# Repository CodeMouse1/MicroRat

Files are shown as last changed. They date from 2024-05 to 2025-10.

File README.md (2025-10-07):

# MicroRat: Eine technische Dokumentation

<div align="center">
	

<div align="left">

Dieses Repository dokumentiert und bündelt das Projekt MicroRat – eine an der Micromouse orientierte Plattform für Studierenden der BHT.
Es stellt ein vollständiges Paket aus Hardware und Software-Komponenten bereit und soll als Grundlage für eigene Projekte, Experimente und Weiterentwicklungen dienen.
<div align="center">
	
<div align="left">
<br>
Wenn der Begriff einer Micromouse unbekannt ist findet man unter diesem Link ein Erläuterungsvideo:
[▶️](https://www.youtube.com/watch?v=ZMQbHMgK2rw)
<br>

## Technische Beschreibung
Micromouse ist ein internationaler Robotik-Wettbewerb, bei dem kleine, autonome Roboter ein Labyrinth selbstständig erkunden und den schnellsten Weg zum Ziel finden müssen.
Die Fahrzeuge agieren vollkommen ohne externe Hilfe und entscheiden selbstständig, wie sie Hindernisse und Wände erkennen.

_Die MicroRat soll als Einstieg in diese Thematik dienen._

**Hardware Umsetzung**

Das Aussehen einer Micromouse hängt stark vom jeweiligen Erbauer ab. Die MicroRat ist bewusst so gestaltet, dass sie grundlegende Funktionen mit einfacher Benutzbarkeit und Programmierbarkeit kombiniert.
Zur Umgebungserfassung kommen folgende Sensoren zum Einsatz:
###### Sensorik
- SHARP Infrarot-Sensoren, jeweils im 90°-Winkel senkrecht zu den Wänden montiert
- HC-SR04 Ultraschall-Sensor an der Vorderseite

###### Antrieb
- DC-Motoren mit Encodern für Antrieb und Drehzahlerfassung 

###### Stromversorgung
- 2s1p Li-Ion Akkupack für stabile Energieversorgung  

###### Steuerung & Schnittstellen

- XMC-1402 Mikrocontroller, programmierbar über Debug-Connector
- UART Schnittstelle zur Ausgabe der Sensordaten 

<div align="center">

<p float="center">
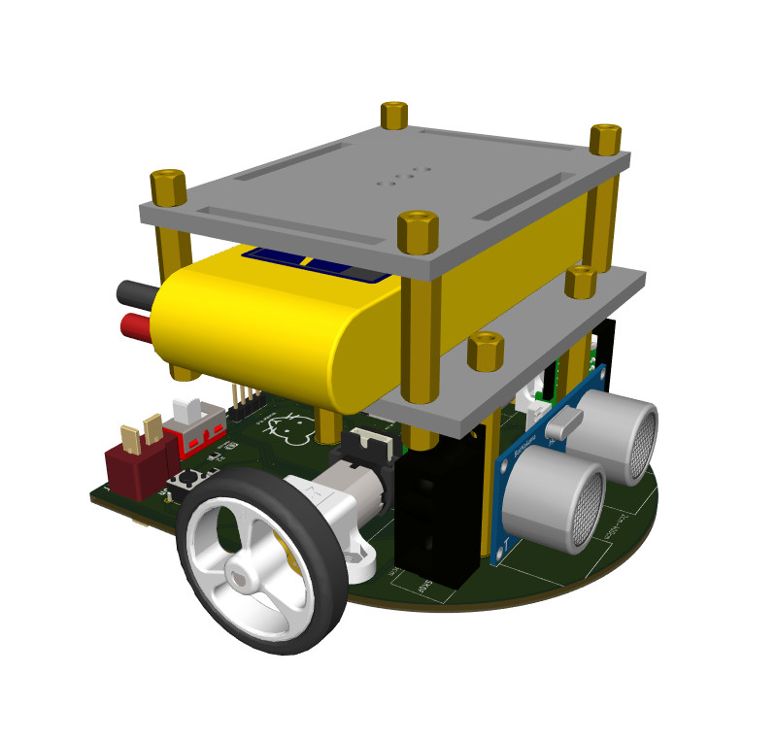
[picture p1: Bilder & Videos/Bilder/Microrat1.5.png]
  
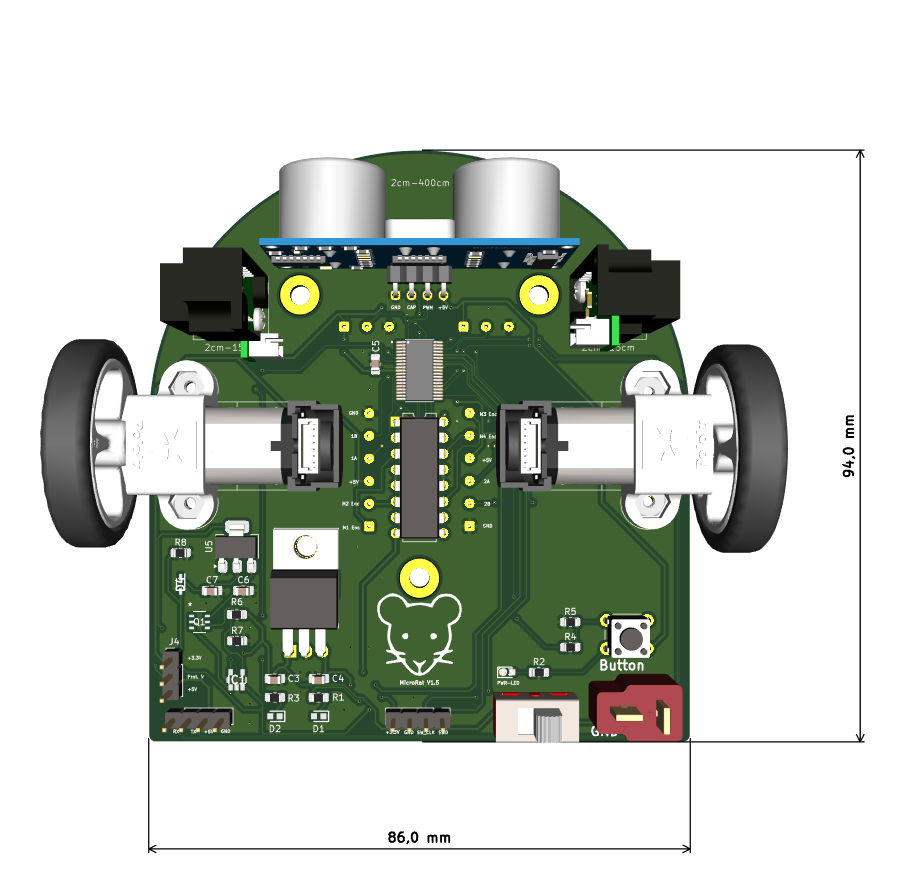
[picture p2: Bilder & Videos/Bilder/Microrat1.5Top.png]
   
</p>
Hier ein Link zu einer 3D Ansicht: [3D-Modell](https://a360.co/3VB2RBQ)
<div align="left">
<br>

**Software-Architektur**

Die MicroRat wird über den XMC-1402 Mikrocontroller gesteuert, der Sensoren ausliest, Motoren ansteuert und die Labyrinthnavigation übernimmt.

###### Entwicklungsumgebung
- **Sprache:** C
- **IDE:** DAVE™ 
- **Debugging:** Über den Debug-Connector des XMC4500

###### Hauptfunktionen
- **Sensordaten-Auswertung:** IR- und Ultraschallsensor erkennen Wände und Hindernisse
- **Motorsteuerung:** Drehzahlgeregelte Ansteuerung der DC-Motoren mittels PD-Regler
- **Labyrinth-Algorithmus:**
	- Wandfolger (links/rechts), kartografiert
	- Floodfill, Optimierung des schnellsten Weges zum Ziel
- **Kommunikation:** Sensordaten über UART für Debugging & Logging
<div align="center">

<p float="center">
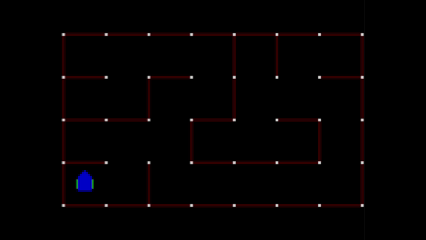
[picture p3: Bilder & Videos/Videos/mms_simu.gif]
  
</p>
<div align="left">

## Verwendung von KiCad 8.0
<div align="center">
	
<div align="left">
Für dieses Projekt haben wir KiCad 8.0 gewählt aus folgenden Gründen:
<br/><br/>

- **Fortschrittliche Funktionen:** Bietet erweiterte Tools für Schaltplanerstellung und Leiterplattendesign.
- **Open-Source-Software:** Kostenfrei und kontinuierlich verbessert durch eine große Community.
- **Plattformübergreifende Unterstützung:** Ermöglicht nahtlose Zusammenarbeit unabhängig vom Betriebssystem.

- **Kompatibilität und Exportmöglichkeiten:** Unterstützt viele Dateiformate und erleichtert die Integration mit anderen Tools.

Für eine grundlegende Einführung in KiCad bitte dieser Ratte folgen: [🐀](https://docs.kicad.org/)

## Anleitung

### Dave IDE 
<div align="center">
	
<div align="left">
<br>

DAVE IDE (Digital Application Virtual Engineering) ist eine benutzerfreundliche Entwicklungsumgebung für Mikrocontroller und eingebettete Systeme. Sie bietet Programmierung, Debugging und Analyse in einer Plattform.

###### Hauptfunktionen:

- **Projektverwaltung:** Projekte erstellen, importieren und konfigurieren.
- **Code-Editor:** Syntax-Highlighting, App-Help und Fehlererkennung.
- **Debugging:** Breakpoints setzen, Schritt-für-Schritt-Debugging, Variablen überwachen.

##### Erste Schritte mit DAVE IDE
- **Installation:**[⬇️](https://softwaretools.infineon.com/tools/com.ifx.tb.tool.daveide)
- **Projekt importieren:** Datei → Importieren → ZIP auswählen.

### Micromouse Simulator
<div align="center">
	
<div align="left">
<br>
Zum einfachen Testen und Erproben von Micromouse-Software ohne physische Hardware wird die Nutzung des MMS-Simulators empfohlen, mit dem Labyrinthe virtuell erstellt und Algorithmen sicher ausprobiert werden können: [Micromouse Simulator](https://github.com/mackorone/mms)

## Lizenzinformationen
Dieses Projekt ist Lizensiert unter der CC 4.0 Lizenz
https://creativecommons.org/licenses/by/4.0/

## Mitwirken
Wir freuen uns auf eure Erweiterungen! Wenn du an diesem Projekt mitarbeiten möchtest, folge bitte diesen Schritten:

1. **Fork dieses Repository**: Klicke oben rechts auf die Schaltfläche "Fork", um eine Kopie des Repositories in deinem GitLab-Konto zu erstellen.

2. **Clone das Forked Repository**: Klone dein geforktes Repository auf deinen lokalen Rechner.
    ```bash
    git clone https://github.com/dein-username/dein-repository.git
    ```

3. **Erstelle einen neuen Branch**: Erstelle einen neuen Branch für deine Arbeit.
    ```bash
    git checkout -b mein-neuer-branch
    ```

4. **Nimm deine Änderungen vor**: Führe die gewünschten Änderungen durch und committe sie.
    ```bash
    git add .
    git commit -m "Beschreibe deine Änderungen"
    ```

5. **Push deine Änderungen**: Push deine Änderungen zu deinem Fork.
    ```bash
    git push origin mein-neuer-branch
    ```

6. **Erstelle einen Pull Request**: Gehe zu deinem geforkten Repository auf GitLab und klicke auf die Schaltfläche "New Pull Request", um deine Änderungen zur Überprüfung einzureichen.

## Entwickler

Hardware & Software: Marcus Stake Alvarado

Ursprüngliches Hardware-Design: Nico Hinrichs

Ansprechprofessor: Prof. Dipl.-Ing. Koshan Mahdi

<div align="center">

**Viel Spaß mit der MicroRat**



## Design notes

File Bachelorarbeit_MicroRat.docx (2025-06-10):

Entwicklung und Implementierung eines effizienten Pfadfindungsalgorithmus für autonome Micromouse-Roboter in labyrinthartigen Umgebungen

Zwölfwöchige Abschlussarbeit im Rahmen der Prüfung

im Bachelorstudiengang Elektromobilität

an der Berliner Hochschule für Technik

vorgelegt am: 30.06.2025

von: Marcus Stake Alvarado

Matrikelnummer: 929605

1. Betreuer: Prof. Dipl.-Ing. Koshan Mahdi
2. Betreuer: Prof. Dr. Sven Graupner.

Berliner Hochschule für Technik

Vorwort

Diese Bachelorarbeit wäre ohne die Unterstützung von Prof. Dipl.-Ing. Koshan Mahdi und Prof. Dr. Sven Graupner nicht möglich gewesen. Mein besonderer Dank gilt ihnen für ihre fachliche Unterstützung, ihre wertvollen Anregungen sowie die vertrauensvolle Begleitung während der gesamten Bearbeitungszeit. Ein weiterer Dank richtet sich an Frank Stenzel, der mich insbesondere beim Aufbau meines Projektes tatkräftig unterstützt hat.

Diese Arbeit verwendet das generische Maskulinum, um die Lesbarkeit zu erhalten. Es sind dabei ausdrücklich alle Geschlechteridentitäten mitgemeint.

# Akronyme

C | Programmiersprache C
DAVE IDE | Development and Application Virtual Environment Integrated Development Environment
IR | Infrarot – ein Sensor, der zur Erkennung von Wänden und Hindernissen in der Nähe verwendet wird
Micromouse | Ein autonomer Roboter, der Labyrinthe selbstständig navigiert und deren Lösung findet
MicroRat | Bezeichnet das Projekt, das auf der Micromouse-Hardware basiert und speziell für den Einstieg in Embedded Systems und autonome Systeme konzipiert wurde.
PWM | Pulse Width Modulation - Ein Verfahren zur Erzeugung analog wirkender Spannungswerte durch digitale Signale, das unter anderem zur Geschwindigkeitsregelung von Motoren eingesetzt wird.
SLAM | Simultaneous Localization and Mapping (Simultane Lokalisierung und Kartierung)
UART | Universal Asynchronous Receiver-Transmitter – eine serielle Schnittstelle zur Kommunikation zwischen der MicroRat und externen Geräten
UML | Unified Modeling Language
US | Ultraschall – ein Sensor, der zur Messung von Abständen zu Hindernissen verwendet wird, insbesondere für die Frontnavigation der MicroRat.

# Glossar

Autonome Systeme | Systeme, die ohne menschliche Eingriffe Entscheidungen treffen und Aufgaben ausführen können
Eingebettete Systeme | Spezialisierte Computer, die in Geräten eingebaut sind, um bestimmte Funktionen auszuführen
Sensorik | Technik und Geräte, die physikalische Größen wie Temperatur, Abstand oder Bewegung messen
Aktuatorik | Technik und Geräte, die auf Basis von Sensorinformationen eine physikalische Bewegung oder Änderung hervorrufen
Mikrocontroller | Ein kleiner Computer auf einem einzigen Chip, der in eingebetteten Systemen verwendet wird
Timer/Interrupts | Mechanismen in Mikrocontrollern, die bestimmte Aktionen basierend auf Zeit oder Ereignissen auslösen
Wandverfolgung | Eine Navigationsstrategie für Roboter, bei der der Roboter kontinuierlich eine Wand entlang fährt, um sich zu orientieren
Maze-Solver | Ein Algorithmus oder eine Methode, die dazu verwendet wird, ein Labyrinth zu lösen
Git-Repository | Ein Speicherort für den Quellcode, der Versionierung und Zusammenarbeit ermöglicht.
Modularität | Der Aufbau eines Systems, bei dem einzelne Komponenten unabhängig voneinander entwickelt und ersetzt werden können.

# 1 Einleitung

Die autonome Navigation von Fahrzeugen und Robotern ist ein zentraler Pfeiler der modernen Elektromobilität. Eine der größten Herausforderungen in diesem Feld ist die Fähigkeit, sich in komplexen und unbekannten Umgebungen selbstständig zu orientieren [1]. Micromouse-Wettbewerbe, in deren Rahmen kleine Roboter labyrinthartige Strukturen durchqueren, stellen eine hervorragende und praxisnahe Plattform zur Erforschung grundlegender Prinzipien der autonomen Pfadfindung in einem kontrollierten Rahmen dar [2]. Die in diesem Kontext entwickelten effizienten Pfadfindungsalgorithmen sind nicht nur für diese spezifischen Roboter von Relevanz, sondern liefern auch wertvolle Erkenntnisse für die intelligente Steuerung und Routenoptimierung in größeren Systemen des autonomen Fahrens [3].

Der Fokus dieser Bachelorarbeit liegt auf der MicroRat-Plattform, einer im Rahmen einer studentischen Initiative an der Berliner Hochschule für Technik entwickelten Hardware-Komponente. Die Arbeit konzentriert sich explizit auf die Softwareentwicklung zur Pfadfindung, um die MicroRat zu einem voll funktionsfähigen Navigationssystem zu machen. Hierfür wurde zudem ein eigenes Labyrinth entworfen und gebaut, um eine maßgeschneiderte und reproduzierbare Testumgebung zu schaffen.

Die effiziente Pfadfindung in komplexen Labyrinthen stellt autonome Roboter vor signifikante Herausforderungen. Obwohl einfache Strategien wie der Wall Follower in grundlegenden Umgebungen effektiv sein können, stoßen sie bei zunehmender Komplexität oft an ihre Grenzen hinsichtlich der Lösungsgeschwindigkeit und Effizienz [4]. Dies ist insbesondere vor dem Hintergrund der limitierten Rechenressourcen und Sensorkapazitäten kleiner autonomer Plattformen wie der MicroRat zu berücksichtigen [5].

Ziel dieser Bachelorarbeit ist daher die Entwicklung und Implementierung von Wall Follower Algorithmen für die MicroRat-Plattform, gefolgt von einer Pfadoptimierung mittels des Flood Fill Algorithmus nach der Erkundung des Labyrinths. Ein zentraler Aspekt dieser Arbeit ist die Konzeption einer klaren und nachvollziehbaren Softwarearchitektur. Diese soll nicht nur die optimale Anpassung der Algorithmen an die bestehende Hardware und die reibungslose Integration mit den vorhandenen Sensoren und der Steuerungseinheit sicherstellen, sondern auch als verständliche Grundlage für zukünftige studentische Projekte an der MicroRat-Plattform dienen.

## 1.1 Motivation

Die Motivation für diese Bachelorarbeit basiert auf dem besonderen Reiz von Micromouse-Robotern, die verschiedene Kernbereiche wie Elektrotechnik, Informatik und Robotik auf einzigartige Weise vereinen. Die Interdisziplinarität des Themas bietet eine ideale Grundlage für eine Vertiefung im Rahmen des Studiengangs Elektromobilität.

Ein wesentliches Ziel bestand zudem darin, einen praktischen Beitrag zur MicroRat-Plattform zu leisten. Die Konzeption einer robusten und nachvollziehbaren Gesamtbasis (Hard- und Software) zielt darauf ab, zukünftigen Studierenden den Einstieg in die autonome Robotik zu erleichtern. Die geschaffene Plattform dient als Fundament, um typische Sensoren, Komponenten und Navigationsalgorithmen zu erlernen und weitere Entwicklungen auf der MicroRat zu ermöglichen.

## 1.2 Problemstellung

Die effiziente Navigation autonomer Roboter in komplexen Labyrinthen ist mit spezifischen Herausforderungen verbunden. Bei der Erkundung unbekannter Umgebungen können grundlegende Strategien wie der Wall Follower eine erste Orientierung bieten, jedoch sind sie allein hinsichtlich der Lösungsgeschwindigkeit und Effizienz bei steigender Komplexität oft unzureichend. Diese Limitierungen werden zusätzlich durch die begrenzten Rechenressourcen und Sensorkapazitäten kleiner autonomer Plattformen, wie der in dieser Arbeit genutzten MicroRat, verstärkt. Es bedarf somit einer Kombination aus geeigneten Erkundungs- und Optimierungsalgorithmen, die diesen Restriktionen gerecht werden und eine effiziente Pfadfindung ermöglichen.

Des Weiteren existierte bisher keine zentrale und umfassende studentische Plattform (bestehend aus Hard- und Software), die speziell darauf ausgelegt ist, Studierenden den Einstieg in die Entwicklung und Erprobung autonomer Navigation zu erleichtern. Dies erschwert es, die notwendigen praktischen Erfahrungen im Zusammenspiel von Sensorik, Bewegungsteuerung und komplexen Navigationsalgorithmen zu sammeln und eigenständig weiterzuentwickeln. Eine schnelle und zuverlässige Pfadfindung in anspruchsvollen Umgebungen erfordert daher nicht nur die Implementierung leistungsfähiger Algorithmen, sondern auch die Bereitstellung einer zugänglichen und nachvollziehbaren Gesamtplattform, die als Basis für zukünftige Projekte und Lehrzwecke dienen kann.

## 1.3 Zielsetzung

Das übergeordnete Ziel dieser Bachelorarbeit ist die Entwicklung und Implementierung einer effizienten und nachvollziehbaren Navigationslösung für die MicroRat-Plattform, die sowohl technische Herausforderungen meistert als auch als didaktische Grundlage dient. Um dieses Hauptziel zu erreichen, werden folgende spezifische Ziele verfolgt:

- Entwicklung und Implementierung von Wall Follower Algorithmen für die MicroRat-Plattform zur initialen Labyrinth Exploration.
- Pfadoptimierung der erkundeten Labyrinthe mittels des Flood Fill Algorithmus, um die Effizienz der Navigation zu maximieren.
- Konzeption und Umsetzung einer klaren und modularen Softwarearchitektur, die eine optimale Anpassung der Algorithmen an die bestehende MicroRat-Hardware ermöglicht und die reibungslose Integration aller Sensoren und der Steuerungseinheit sicherstellt.
- Entwurf und Bau eines maßgeschneiderten Labyrinths als dedizierte Testumgebung für die Validierung der entwickelten Navigationsalgorithmen.
- Bereitstellung einer vollständigen und dokumentierten Gesamtplattform (Hard- und Software), die zukünftigen Einstieg in die Entwicklung und Erprobung autonomer Micromouse-Roboter ermöglicht und als fundierte Basis für weiterführende Projekte und Lehre an der Berliner Hochschule für Technik dienen kann.

## 1.4 Vorgehensweise

Die vorliegende Arbeit wird in mehrere Kapitel unterteilt:

Kapitel 1: Einleitung
Dieses Kapitel führt in die Problemstellung, die Zielsetzung und die Motivation der Arbeit ein. Es erläutert den Kontext und die Relevanz des Projekts sowie die Vorgehensweise vor.

Kapitel 2: Grundlagen
In diesem Kapitel werden die theoretischen Grundlagen und relevanten Konzepte erläutert, die für das Verständnis der Arbeit erforderlich sind.

Kapitel 3: Anforderungsanalyse
In diesem Kapitel wird die Zielgruppe des Projekts analysiert, für die die Software entwickelt wurde. Auf Grundlage dieser Zielgruppenanalyse werden die spezifischen Anforderungen an die zu entwickelnde Software abgeleitet und formuliert.

Kapitel 4: Entwurf
In diesem Kapitel wird der Entwurf des Pfadfindungsalgorithmus für den autonomen Micromouse-Roboter, die Softwarearchitektur sowie die Struktur der labyrinthartigen Umgebung beschrieben.

Kapitel 5: Implementierung
In diesem Kapitel wird die Implementierung der entwickelten Software detailliert beschrieben. Es wird auf die Struktur des Projekts eingegangen, die wesentlichen Schritte der Code-Entwicklung erläutert.

Kapitel 6: Validierung und Evaluation
In diesem Kapitel wird die Umsetzung der im Kapitel 3 festgelegten Anforderungen überprüft. Die tatsächliche Realisierung wird mit den definierten Anforderungen abgeglichen und hinsichtlich ihrer Funktionsfähigkeit sowie Effektivität evaluiert.

Kapitel 7: Fazit und Ausblick
In diesem Kapitel werden die Ergebnisse der Arbeit zusammengefasst und die Zielerreichung reflektiert. Zudem werden mögliche Perspektiven für zukünftige Entwicklungen und Optimierungen des entwickelten Systems aufgezeigt.

# 2 Grundlagen

## 2.1 Micromouse-Plattform

Ein Micromouse ist ein autonomer, selbstständiger Roboter, der entwickelt wird, um das Zentrum eines Labyrinths in der kürzest möglichen Zeit zu erreichen. Der Roboter besteht typischerweise aus drei Hauptsystemen: dem Antriebssystem, einem Array von Sensoren und dem Steuerungssystem. Diese Systeme arbeiten zusammen, um dem Roboter zu ermöglichen, das Labyrinth zu erkunden, Wände zu erkennen und die optimale Route zu finden. Die grundlegenden Komponenten umfassen Motoren für den Antrieb, Steuermechanismen für das Drehen und Lenken, Sensoren zur Erkennung von Labyrinthwänden sowie eine Steuerlogik, die die Bewegungen überwacht und die Navigation im Labyrinth ermöglicht. Darüber hinaus ist der Micromouse mit Batterien ausgestattet, die die notwendige Energie für seine Operationen liefern. Es vereint interdisziplinäre ingenieurwissenschaftliche Aspekte, darunter Elektronik, Mechanik, Steuerungstechnik und Programmierung. Die Entwürfe der erfolgreichsten Micromouse-Roboter erfordern eine präzise Abstimmung der Komponenten, um das Gewicht, die Geschwindigkeit und die Energieeffizienz zu optimieren. Besonders hervorzuheben ist die Bedeutung von Entscheidungsfindungsalgorithmen, die es dem Roboter ermöglichen, in unbekannten Umgebungen autonom zu navigieren. Für Anfänger im Bereich Micromouse wird häufig mit einfachen Logiken begonnen, wie etwa der Wandfolgetechnik, die später durch anspruchsvollere Algorithmen wie Pfadfindungsstrategien ersetzt wird [1].

### 2.1.1 Geschichte der Micromouse-Wettbewerbe

Die Micromouse-Wettbewerbe wurden erstmals 1979 von der IEE Spectrum Magazine ins Leben gerufen, nachdem 1972 die Idee eines mechanischen Rennmaus-Wettbewerbs entstand. Der erste Wettbewerb fand 1979 in New York statt, bei dem 6.000 Einsendungen verzeichnet wurden, aber nur 15 Mäuse tatsächlich teilnahmen. Die Wettbewerbe begannen auf 8x8-Labyrinthen, wobei die schnellsten Mäuse Zeiten von etwa 30 Sekunden erreichten [2]. Der Sieger war 'Moonlight Flash', eine einfache Wandfolgemaschine. In den folgenden Jahren wurden die Wettbewerbsregeln zunehmend anspruchsvoller, was dazu führte, dass die Entwickler intelligentere Mäuse bauten, die in der Lage waren, das Labyrinth eigenständig zu lösen [1].

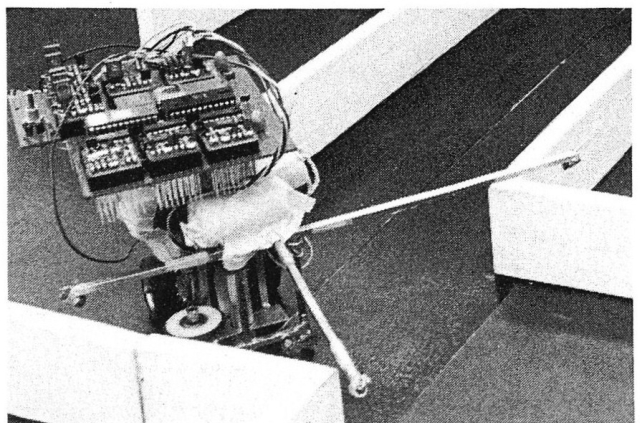
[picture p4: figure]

Abbildung 1: „Moonlight Flash“ – Micromouse, 1979

Die erste europäische Micromouse-Veranstaltung fand 1980 in London statt, und 1985 wurde der erste Welt-Micromouse-Wettbewerb in Japan ausgetragen. Ab den 1990er Jahren begannen Micromouse-Clubs an Schulen zu entstehen, und 1991 wurden die Wettbewerbsregeln geändert, um nicht nur die Geschwindigkeit, sondern auch die Zuverlässigkeit der Mäuse zu betonen [1]. Heute, mehr als vier Jahrzehnten später, haben sich die Wettkämpfe weltweit verbreitet und sind besonders in Japan, Taiwan, Indonesien, Großbritannien und den USA populär. Die Labyrinthe bestehen inzwischen aus 16x16 Zellen, und die besten Mäuse erreichen Rennzeiten von weniger als 7 Sekunden bei Strecken von über 70 Zellen. Diese Rekordzeiten entsprechen einer Geschwindigkeit von 2 bis 4 Metern pro Sekunde. Die Wettbewerbe haben sich so weit entwickelt, dass führende Micromouse-Designer das ganze Jahr über an Verbesserungen im Bereich der Hundertstelsekunden arbeiten [2].

Im Jahr 2009 entschieden die Veranstalter in Japan, eine neue Herausforderung zu schaffen: Die Half-Size Micromouse. Die Regeln und das Ziel bleiben nahezu gleich, aber die Baugröße wurde auf die Hälfte reduziert. Diese kleinere Variante stellt die Designer vor neue Herausforderungen, insbesondere im Hinblick auf die Miniaturisierung der Komponenten. Dank der Entwicklungen in der Smartphone- und Drohnentechnologie ist es mittlerweile möglich, bemerkenswert kompakte und komplexe Roboter zu bauen [2].

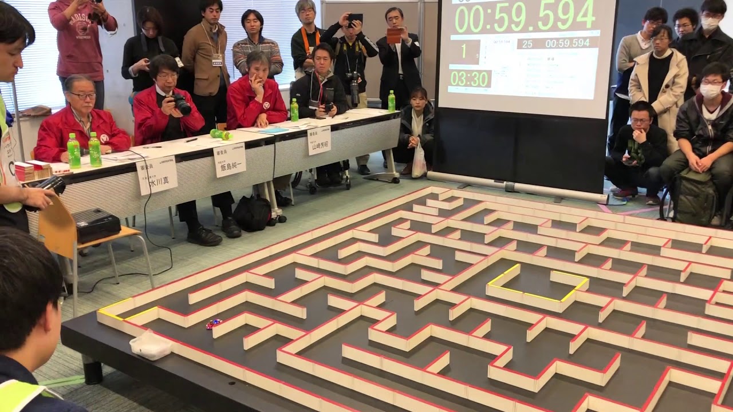
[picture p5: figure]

Abbildung 2: „赤い彗星 (Red Comet)“ – 1. Platz, All Japan Classic Micromouse Contest 2017, von Utsunomiya-san

## 2.2 Aufbau der MicroRat Plattform

Die Hardware eines Micromouse besteht im Wesentlichen aus fünf Hauptkomponenten: Sensoren, Leiterplatte, Energieversorgung, Mikrokontroller und Antriebssystem (siehe Abb. 3). Diese Systeme arbeiten eng zusammen, um eine effiziente und präzise Funktionalität zu gewährleisten [1].

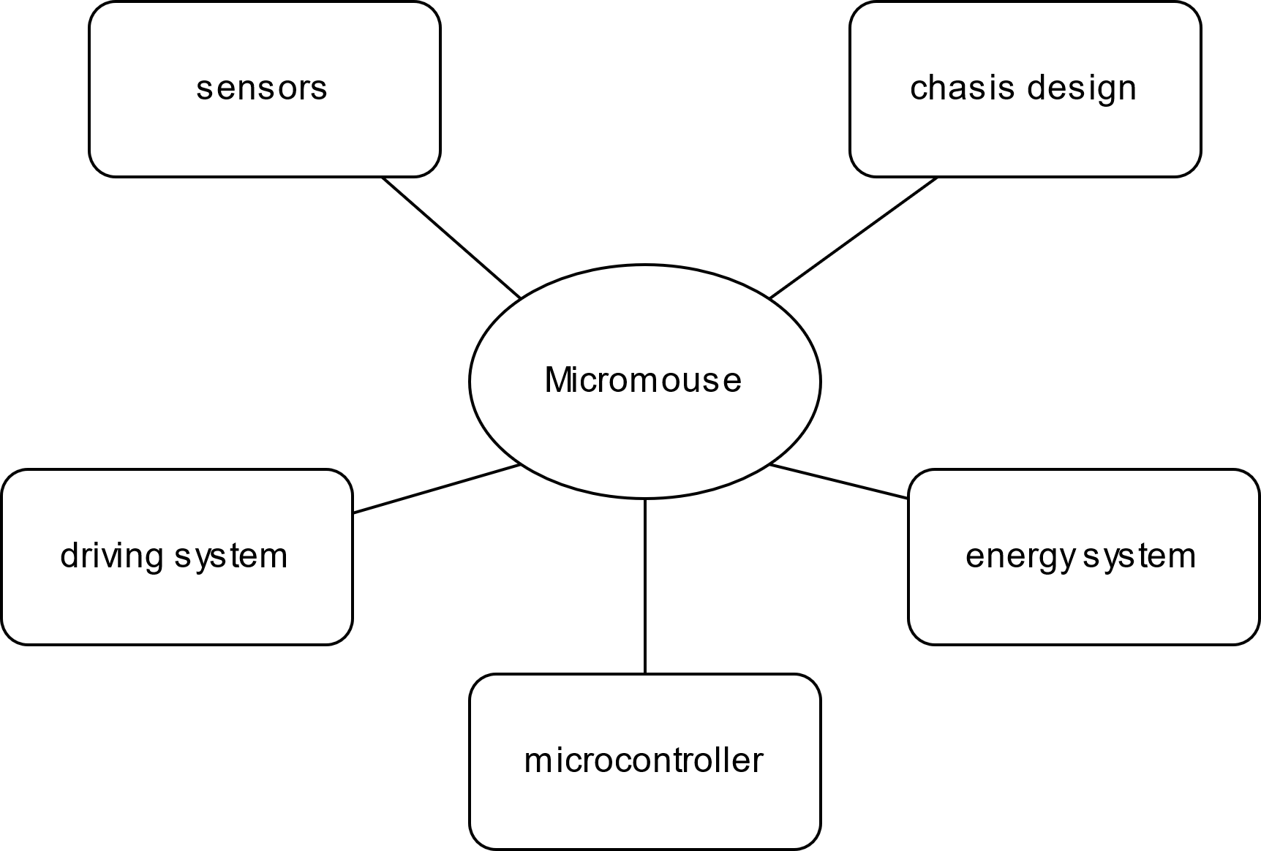
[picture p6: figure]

Abbildung 3: Blockdiagramm einer Micromouse Allgemein

Die MicroRat-Plattform, die bereits im 6. Semester im Rahmen der Steuergeräteentwicklung konzipiert und entwickelt wurde, basiert auf diesen grundlegenden Prinzipien. In den folgenden Abschnitten wird auf die einzelnen Komponenten der MicroRat näher eingegangen, um die Funktionalität und Integration der Hardware zu verdeutlichen.

### 2.2.1 Sensorik

Die Sensoren eines autonomen mobilen Roboters sind entscheidend für die Wahrnehmung und Interaktion mit seiner Umgebung. In einer Micromouse, wie auch in anderen autonomen Systemen, ermöglichen Sensoren das Erfassen von Umgebungsdaten, die für die Navigation und Entscheidungsfindung unerlässlich sind. Ohne diese Wahrnehmungsfähigkeit wären die erfassten Daten lediglich bedeutungslose Zahlen, die keinen Einfluss auf das Verhalten des Roboters hätten [3]. Ähnlich wie in biologischen Systemen, in denen visuelle Wahrnehmung eine wichtige Quelle der Navigation und Planung darstellt [3], nutzt die MicroRat Sensoren zur Umgebungserfassung.

Die Sicht der MicroRat wird durch eine Kombination aus Licht- und Schallsensoren simuliert, die es dem Roboter ermöglichen, auf Objekte und Veränderungen in seiner Nähe zu reagieren. Besonders in der Navigations- und Hindernisvermeidungsphase spielen Infrarot- und Ultraschallsensoren eine entscheidende Rolle, da sie dem Roboter helfen, Entfernungen präzise zu messen und Hindernisse zuverlässig zu detektieren [4]. Im Folgenden werden wir uns näher mit den Funktionen und Vorteilen von Infrarot- und Ultraschallsensoren in autonomen Systemen wie der MicroRat befassen.

Infrarot Sensoren (IR)

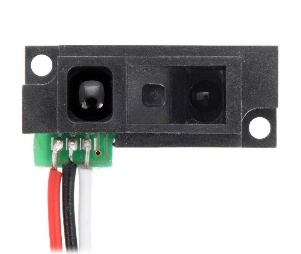
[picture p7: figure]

Abbildung 4: Infrarotsensor GP2Y0A51SK0F

Infrarotsensoren werden häufig in der Robotik eingesetzt, um Entfernungen zu messen, und sind besonders nützlich bei der Hindernisvermeidung. Im Vergleich zu Ultraschallsensoren sind sie kostengünstiger und reagieren schneller. Allerdings weisen IR-Sensoren nichtlineare Charakteristiken auf und ihre Leistung hängt von den Reflexionseigenschaften der Oberflächen ab. Das bedeutet, dass die Beschaffenheit der Oberfläche, die das Infrarotlicht reflektiert oder absorbiert, bekannt sein muss, um die Sensormessungen korrekt zu interpretieren [5]. Die Funktionsweise eines IR-Sensors basiert auf zwei Hauptkomponenten: einem Infrarot-LED-Emitter und einem Infrarot-Fotodetektor. Der Emitter sendet Infrarotlicht aus, das von Objekten in der Umgebung reflektiert wird. Das reflektierte Licht trifft auf einen Positionsdetektor (PSD). Je nach Entfernung des Objekts verändert sich der Einfallswinkel des reflektierten Lichts, wodurch sich die Auftreffposition auf dem Detektor verschiebt. Der Sensor ermittelt aus dieser Position die Entfernung zum Objekt mittels Triangulation [6]. Ein spezifischer Sensor, der in der MicroRat verwendet wird, ist der Sharp GP2Y0A51SK0F. Dieser Sensor verwendet die zuvor beschriebene Triangulationsmethode, bei der der Abstand durch das reflektierte Infrarotlicht bestimmt wird. Der Sensor führt die Entfernungsmessung intern durch. Eine direkte Berechnungsformel existiert nicht; stattdessen korreliert die analoge Ausgangsspannung mit der Entfernung entsprechend einer herstellerspezifischen Kennlinie [6].

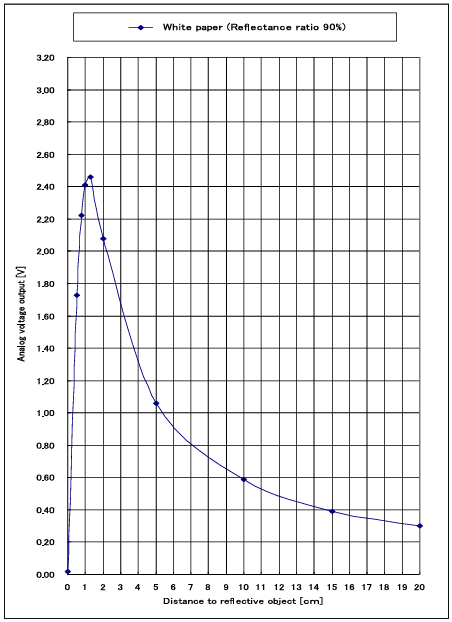
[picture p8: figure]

Abbildung 5: Spannung in Relation zur Distanz des Sharp GP2Y0A51SK0F Infrarotsensors

Der GP2Y0A51SK0F bietet eine Reichweite von 2 cm bis 15 cm und liefert eine hohe Auflösung bei kurzen Distanzen. Das Ausgangssignal des Sensors ist eine analoge Spannung, die direkt mit der Entfernung korreliert [6]. Diese Spannung wird von einem Analog-Digital-Wandler (ADC) in der MicroRat aufgenommen, der das analoge Signal in digitale Werte umwandelt. Diese digitalen Werte können dann vom Mikrocontroller der MicroRat-Plattform weiterverarbeitet werden. In der MicroRat-Plattform sind zwei dieser IR-Sensoren in einem 45°-Winkel an der Vorderseite montiert. Diese Position ermöglicht es, die Wände des Labyrinths zu erfassen und Hindernisse effektiv zu erkennen, was eine präzise Navigation innerhalb der engen Gänge ermöglicht.

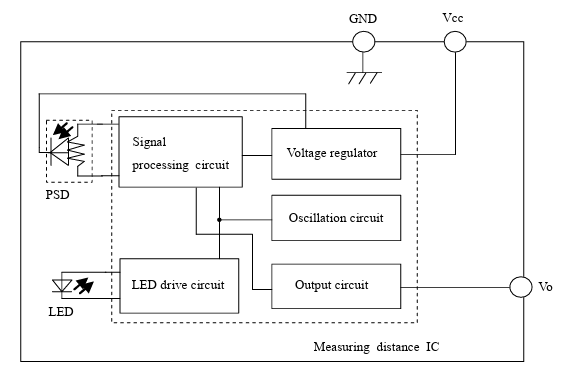
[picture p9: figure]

Abbildung 6: Schaltplan GP2Y0A51SK0F

Ultraschallsensor

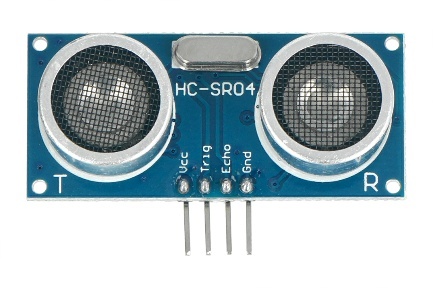
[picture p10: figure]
Ultraschall-Abstandssensor HC-SR04 2-400 cm - SparkFun SEN-15569

Abbildung 7: Ultraschallsensor HC-SR04

Ultraschallsensoren sind in der Robotik weit verbreitet und werden häufig für kontaktlose, mittlere Entfernungsabstände verwendet. Diese Sensoren kommen insbesondere in Navigationssystemen für mobile Roboter und Fahrzeuge zum Einsatz. Ultraschallsensoren nutzen die Time of Flight (TOF) Methode zur Entfernungsmessung, bei der die Zeit gemessen wird, die ein Ultraschallimpuls benötigt, um von einem Sender zu einem Objekt und zurück zum Empfänger zu reisen. Diese Methode ermöglicht eine präzise Entfernungsmessung und ist besonders geeignet für die Hinderniserkennung und -vermeidung [4]. Ein Ultraschallsensor funktioniert, indem er eine Schallwelle mit einer bestimmten Frequenz aussendet. Der Sensor hört dann nach dieser speziellen Schallwelle, die von einem Objekt zurückprallt. Die Zeit, die zwischen dem Senden der Schallwelle und dem Zurückkehren der Schallwelle vergeht, wird dabei erfasst (siehe Abbildung 1) [4].

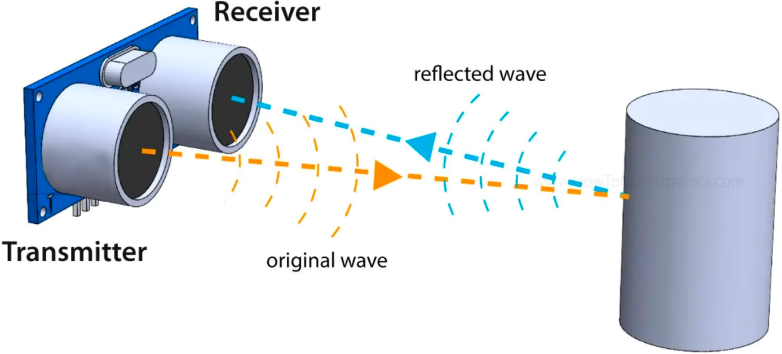
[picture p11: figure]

Abbildung 8: Funktionsweise HC-SR04

Mit dieser Zeitmessung lässt sich die zurückgelegte Strecke berechnen, indem die Geschwindigkeit der Schallwelle (v) mit der gemessenen Zeit (t) multipliziert wird, wie in Gleichung 2.2.1 gezeigt:

d=v*t

Dabei steht d für die zurückgelegte Entfernung, v für die Geschwindigkeit der Schallwelle und t für die benötigte Zeit. Der HCSR04 Ultraschallsensor kann durch Setzen des TRIG-Pins auf HIGH ausgelöst werden, um einen Ultraschallimpuls zu senden. Nachdem der Impuls gesendet wurde, wird der ECHO-Pin automatisch auf HIGH gesetzt. Dieser Pin bleibt so lange auf HIGH, bis der Schallimpuls wieder vom Objekt reflektiert und zum Sensor zurückkehrt. Die Distanz zum Objekt kann berechnet werden, indem man die Zeit misst, in der der ECHO-Pin auf HIGH bleibt. Diese Zeit entspricht der Dauer, die der Schallimpuls für seine Hin- und Rückreise benötigt. Mithilfe dieser Zeit und der Geschwindigkeit des Schalls lässt sich die zurückgelegte Entfernung berechnen [4].

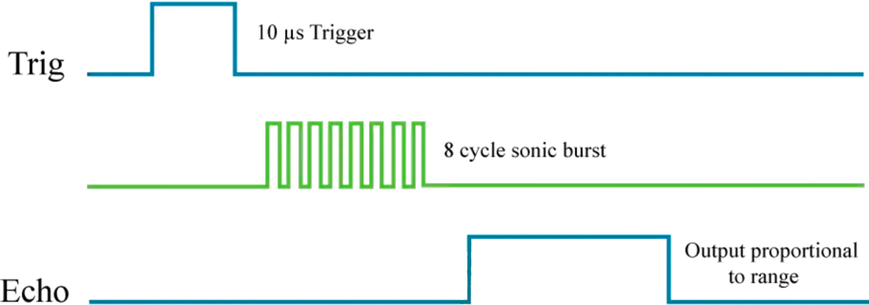
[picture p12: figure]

Abbildung 9: Timing Diagramm HC-SR04

Da die Zeitmessungseinheit des Sensors in Mikrosekunden erfolgt, ist es notwendig, die Schallgeschwindigkeit zu berücksichtigen, die unter Standardbedingungen (bei 20°C und 1013 hPa) etwa 343 Meter pro Sekunde beträgt [3]. Zur praktischen Umrechnung dieser Geschwindigkeit in geeignete Maßeinheiten für die Distanzmessung wird die Schallgeschwindigkeit in Mikrosekunden pro Zentimeter umgerechnet.

Schallgeschwindigkeit=343m/s*(100cm/m*10^6 μs)/s=170.15μs/c

d=(t*170.15μs/cm)/2

Diese Umrechnungen ermöglichen eine präzise Bestimmung der Entfernung in Zentimetern basierend auf der gemessenen Zeit und der bekannten Schallgeschwindigkeit [4]. In der MicroRat-Plattform ist ein HC-SR04 Ultraschallsensor an der Vorderseite montiert, um Hindernisse zu erkennen und eine präzise Navigation zu ermöglichen.

Encoder und Positionsbestimmung

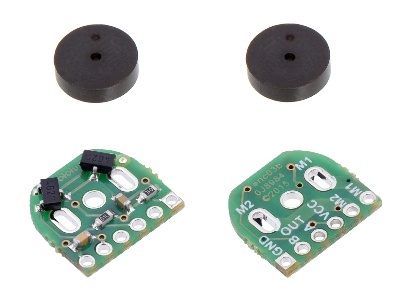
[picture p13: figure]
Pololu - Magnetic Encoder Pair Kit for Micro Metal Gearmotors, 12 CPR, 2.7-18V

Abbildung 10: Encoder Paar in MicroRat

Odometrie bezeichnet die Positions- und Orientierungsbestimmung eines Roboters anhand von Antriebsdaten. Dabei werden Radabstand, Radumfänge und die Motorumdrehungen ausgewertet, um zurückgelegte Strecken und Drehungen zu berechnen [4]. Zur Erfassung der Drehbewegungen werden sogenannte Shaft-Encoder verwendet. Ein Shaft-Encoder ist ein Sensor, der mechanisch mit einer rotierenden Welle (Shaft) verbunden wird und elektrische Signale an ein Logiksystem sendet [7].

Im Rahmen dieser Arbeit wird der Encoder-Typ, der in der MicroRat-Plattform verwendet wird, detailliert betrachtet. Andere Encoder-Typen, die nicht in dieser Plattform zum Einsatz kommen, werden nicht weiter behandelt, da sie für die spezifische Analyse der Odometrie und Navigation des Roboters nicht relevant sind. Bei dem in der MicroRat-Plattform verwendeten Encoder handelt es sich um einen magnetischen inkrementellen Quadratur-Encoder. Im Folgenden wird die Funktionsweise dieses Encoders erläutert.

Magnetische Encoder

Magnetische Encoder nutzen magnetische Felder, die von einem Sensor erfasst werden. Eine magnetische Scheibe oder ein Magnetband dreht sich mit der Welle, und der Sensor registriert die Veränderungen im Magnetfeld, die durch die Bewegung des Lesekopfs entstehen. Diese Änderungen im Magnetfeld werden vom Sensor detektiert und in ein elektrisches Signal umgewandelt [6].

Inkremental und Quadratur Encoder

Ein Inkremental-Encoder ist ein elektromechanisches Bauteil, das lineare oder rotatorische Bewegungen erfasst und zwei Ausgangssignale (A und B) generiert, die bei Bewegung Impulse erzeugen. Anhand der beiden um 90° phasenverschobenen Signale können sowohl Bewegungsänderungen als auch die Bewegungsrichtung bestimmt werden. Im Gegensatz zu einem Absolut-Encoder liefert ein Inkremental-Encoder keine absolute Positionsinformation, sondern lediglich relative Positionsänderungen. Um daraus eine absolute Position zu bestimmen, müssen die ausgegebenen Impulse durch eine geeignete Auswerteelektronik kontinuierlich gezählt werden [7].

Ein Quadratur-Encoder ist eine spezielle Form des Inkremental-Encoders. Er besitzt zwei phasenverschobene Ausgangssignale (A und B), anhand derer nicht nur die Bewegungsänderung, sondern auch die Bewegungsrichtung zuverlässig ermittelt werden kann. Die Phasenlage der Signale ermöglicht es, Drehbewegungen präzise aufzulösen und Richtungswechsel sicher zu erkennen [6].

Funktionsweise des magnetischen inkrementalen Quadratur-Encoders

Der in der MicroRat-Plattform eingesetzte Encoder kombiniert die Prinzipien der magnetischen Erfassung mit der Inkremental- und Quadratur-Technologie. Eine auf der Motorwelle montierte magnetische Scheibe erzeugt ein rotierendes Magnetfeld [6]. Zwei gegenüberliegend angebrachte Hallsensoren erfassen die Veränderungen dieses Magnetfelds und generieren daraus zwei elektrische Signale (A und B), die um 90° phasenverschoben sind [6].

Durch die Auswertung der Signalflanken lässt sich nicht nur die Anzahl der Drehbewegungen (Impulse), sondern auch die Drehrichtung der Welle bestimmen. Die Encoder liefern Impulse, die in Kombination mit der Drehrichtung genutzt werden, um die Bewegungen des Roboters zu erfassen. Diese Informationen werden später zur Berechnung der zurückgelegten Strecke und der Orientierung verwendet.

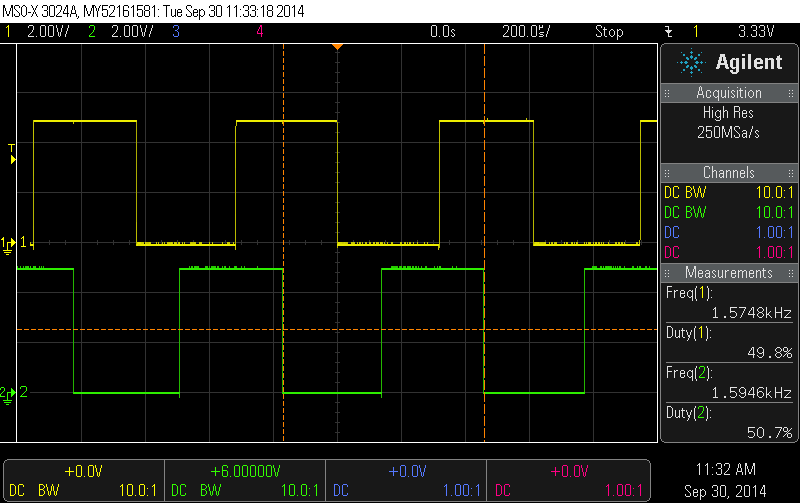
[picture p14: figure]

Abbildung 11: Ausgänge A und B des magnetischen Encoders bei 6V Motorspannung

### 2.2.2 Motorenansteuerung

Der Bewegungsmechanismus eines mobilen Roboters wird maßgeblich durch seinen Antriebsstrang bestimmt, der sich aus den Motoren und dem Motorcontroller zusammensetzt. Die Auswahl der Motoren für eine Micromouse ist von entscheidender Bedeutung, da sie zahlreiche Parameter beeinflusst und sowohl das Gewicht als auch die Leistungsfähigkeit der Micromouse wesentlich bestimmt [8]. Der am häufigsten verwendeter Aktuator in mobilen Robotern ist der Elektromotor, wobei in der Regel Gleichstrommotoren oder Schrittmotoren zum Einsatz kommen. Gleichstrommotoren gelten als besonders einfach zu steuern, da sie bereits durch das Anlegen von Gleichstrom betrieben werden können [8]. Da in der MicroRat-Plattform ein Gleichstrommotor verwendet wird, wird die grundlegende Funktionsweise im Folgenden näher erläutert.

Die grundlegenden Mechanismen der Bewegung sind bei verschiedenen Gleichstrommotoren ähnlicher Natur. Die von diesen Elektromotoren erzeugte Bewegung beruht auf wesentlichen physikalischen Prinzipien wie der Lorentzkraft und der elektromagnetischen Induktion [9]. Gleichstrommotoren mit Bürsten bestehen aus vier Hauptkomponenten: dem stationären Magneten (Stator), dem Rotor, dem Kommutator und den Bürsten. Der Rotor umfasst eine oder mehrere Drahtwicklungen, die um einen ferromagnetischen Kern, meist aus Eisen, gewickelt sind. Über die Bürsten wird elektrischer Strom in die Rotorwicklungen eingespeist. Das dabei entstehende Magnetfeld des Rotors interagiert mit dem Magnetfeld des Stators und erzeugt eine Kraft, die Lorentzkraft, welche den Rotor in Drehbewegung versetzt. Der Stator kann je nach Anforderung entweder aus Permanentmagneten oder Elektromagneten bestehen. Ohne eine gezielte Steuerung der Stromrichtung würde sich das Magnetfeld des Rotors beim Weiterdrehen umkehren, was lediglich zu einer Hin- und Herbewegung führen würde. Um eine kontinuierliche Rotation zu ermöglichen, wird ein Kommutator eingesetzt. Dieser elektrisch und mechanisch segmentierte, leitfähige Ring ist am Rotor angebracht und sorgt zusammen mit den Bürsten dafür, dass die Polarität der Rotorwicklungen periodisch umgekehrt wird. Auf diese Weise wird eine gleichmäßige, kontinuierliche Drehbewegung erreicht [9].

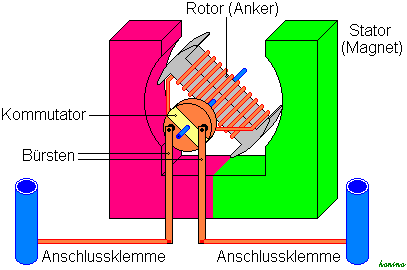
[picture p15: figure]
gleichstrommotor [elweb]

Abbildung 12: PLATZHALTER

Für die MicroRat-Plattform ist es entscheidend, dass der Motor sowohl die Geschwindigkeit als auch die Drehrichtung präzise steuern kann. Die Geschwindigkeit des Motors wird in der Regel über Pulsweitenmodulation (PWM) geregelt. Diese Methode ist besonders effizient, da sie die durchschnittliche Spannung, die an den Motor angelegt wird, durch schnelles Ein- und Ausschalten des Stroms reguliert. Auf diese Weise kann die Drehzahl des Motors gesteuert werden, ohne dass Energie durch Widerstände oder andere Verluste dissipiert wird, wie es bei herkömmlichen Spannungsteilern der Fall wäre.

Um die Drehrichtung des Motors zu ändern, wird in der MicroRat-Plattform eine H-Brücke verwendet. Diese Schaltung besteht aus vier Transistoren, die es ermöglichen, den Stromfluss durch den Motor in beide Richtungen umzuleiten. Indem man die richtigen Transistoren an- und ausschaltet, kann die MicroRat vorwärts oder rückwärts fahren.

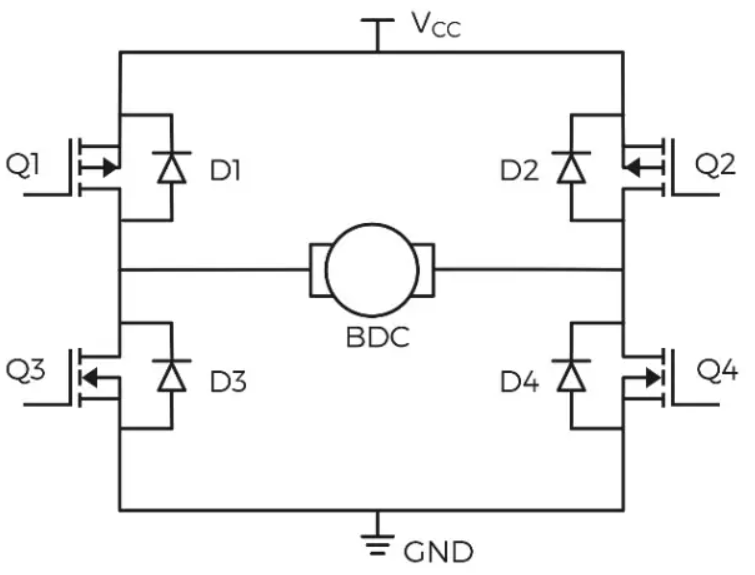
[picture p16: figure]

Abbildung 13: etst

### 2.2.2 Mikrocontroller und DAVE IDE

Das zentrale Steuerelement der MicroRat-Plattform bildet der Mikrocontroller XMC1402-T038X0128 AA von Infineon. Dieser Mikrocontroller basiert auf einem 32-Bit ARM® Cortex®-M0-Prozessorkern und vereint Rechenleistung, Speicher und zahlreiche Peripherieeinheiten in einem kompakten Baustein. Er ist speziell für Embedded-Anwendungen im Bereich Motorsteuerung, Sensoranbindung und allgemeiner Steuerungsaufgaben konzipiert und eignet sich daher ideal für den Einsatz in einer autonomen MikroRat. [Quelle]. Der Mikrocontroller übernimmt im Gesamtsystem zentrale Aufgaben wie die Verarbeitung der Sensordaten, die Ansteuerung der Motoren sowie die Ausführung von Steuer- und Regelalgorithmen. Durch die Vielzahl integrierter Peripherieeinheiten kann die Kommunikation mit der Sensorik sowie die Motorregelung effizient und präzise umgesetzt werden.

Der verwendete Mikrocontroller verfügt über 128 KB Flash-Speicher, 16 KB RAM, sowie eine Vielzahl integrierter Peripherieeinheiten. Dazu zählen unter anderem:

- Ein CORDIC- und Hardware-Divide-Coprozessor (96 MHz) zur effizienten mathematischen Verarbeitung,
- 8 spezielle 16-Bit-Timer mit Totzeit-Generierung,
- Schnittstellen für Hallsensoren und Encoder,
- ein 12-Kanal-12-Bit-ADC mit parallelem Sampling (2x),
- ein BCCU-Modul zur LED-Helligkeits- und Farbsteuerung,
- zwei USIC-Kanäle, die flexibel als SPI, UART, I²C oder IIS konfiguriert werden können,
- Temperatursensor, Pseudozufallszahlengenerator, RTC, Watchdog und weitere Funktionseinheiten.

Der Betriebsspannungsbereich liegt zwischen 1,8 V und 5,5 V, was eine flexible Integration in verschiedene Schaltungsumgebungen ermöglicht. Der Baustein wird im platzsparenden PG-TSSOP-38-Gehäuse verbaut und ist für den Temperaturbereich von −40 °C bis +105 °C spezifiziert. [Quelle]

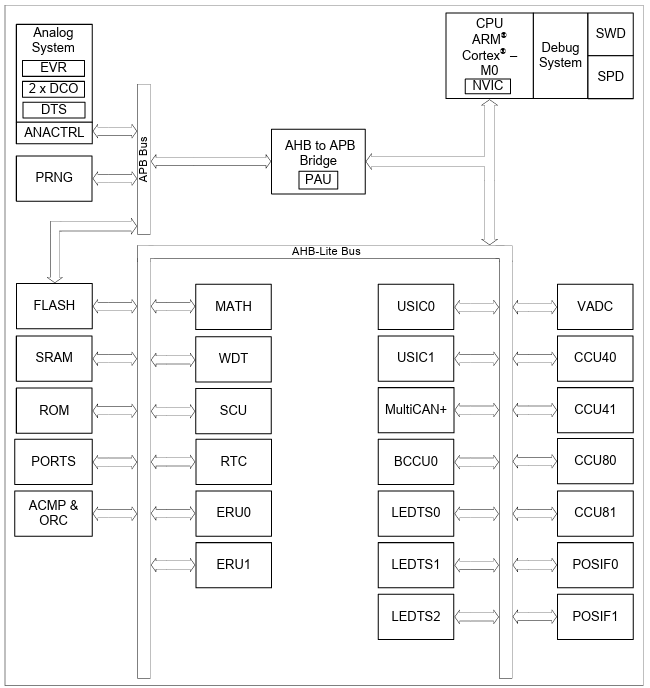
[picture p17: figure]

Abbildung 14: Blockdiagramm XMC1400 Familie

Für die Entwicklung der Software kommt die DAVE IDE (Digital Application Virtual Engineer) von Infineon zum Einsatz. Diese basiert auf Eclipse und wurde speziell für die XMC-Familie entwickelt. Sie unterstützt durch vorgefertigte, konfigurierbare Softwaremodule – sogenannte DAVE Apps – die schnelle und fehlerarme Initialisierung und Ansteuerung von Peripheriekomponenten wie PWM-Ausgänge, ADCs oder Kommunikationsschnittstellen. So können selbst komplexe Aufgaben wie die Ansteuerung von Motoren oder das Erfassen von Sensordaten weitgehend ohne manuelle Registerprogrammierung umgesetzt werden [Quelle]. Durch die Änderung des BMI-Index des Mikrocontrollers ist es nun möglich, den DAVE-Code über die SWD-Schnittstelle (Serial Wire Debug) zu debuggen und direkt auf den Mikrocontroller zu flashen. Der XMC4500 Debugger IC wird für diese Funktionen eingesetzt. [Quelle]

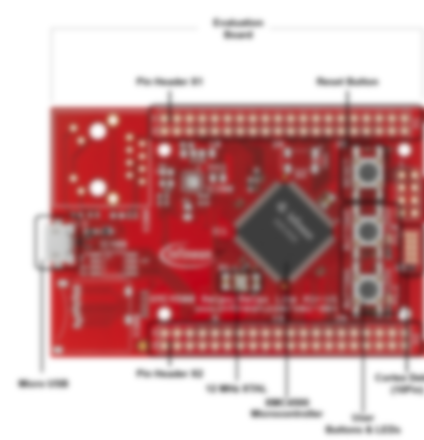
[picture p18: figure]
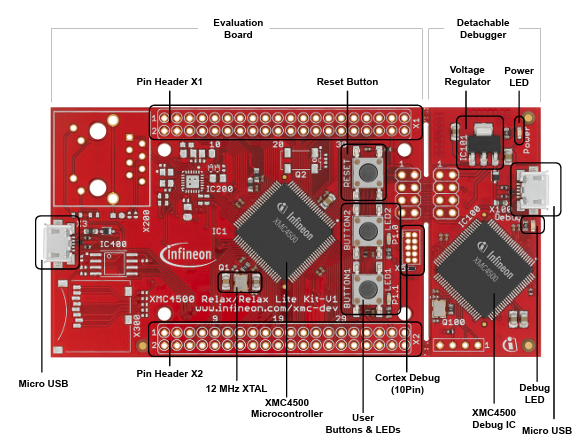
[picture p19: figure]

Abbildung 15: XMC4500 Detachable Debugger

### 2.2.4 Versorgung und PCB

Die Entwicklung des mechanischen Aufbaus, des Akkupacks sowie des PCB-Designs der MicroRat wurde in einem früheren Schritt abgeschlossen und stellt somit nicht den Fokus dieser Arbeit dar. In diesem Abschnitt werden daher die grundlegenden Konzepte dieser Hardwarekomponenten beschrieben, die als Basis für die Softwareentwicklung dienen.

Die MicroRat besteht im Wesentlichen aus einer maßgeschneiderten Leiterplatte, die alle notwendigen Sensoren und Aktoren integriert, sowie einer modularen Plattform, die den Akkupack enthält und die Energieversorgung des Systems sicherstellt.

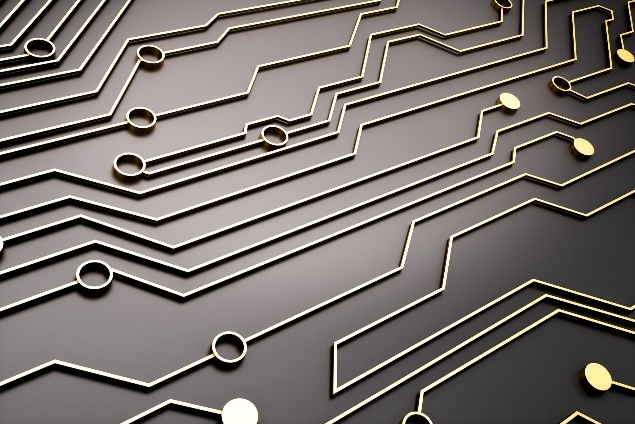
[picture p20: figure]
Abstrakte Leiterplatte

Die Energieversorgung eines Roboters ist ein entscheidender Bestandteil des Gesamtdesigns. Kurz gesagt, ein Roboter benötigt Energie, um zu funktionieren. Daher muss das Versorgungssystem eine Quelle bereitstellen, die genügend Energie liefert, damit der Roboter über einen bestimmten Zeitraum betrieben werden kann, ohne dass die Batterie aufgeladen oder ersetzt werden muss [Quelle]. Die Mehrheit der mobilen Roboter, einschließlich sämtlicher Micromouses, nutzt zur elektrischen Energieversorgung Akkupacks, da diese eine effiziente und praktische Lösung darstellen. Bei der Wahl der Akkuzellen für das Akkupack gibt es eine Vielzahl von Optionen, die hinsichtlich verschiedener Eigenschaften wie Kapazität, Entladekurve und Größe berücksichtigt werden können. In diesem Fall wurde jedoch bereits eine Entscheidung hinsichtlich der Auswahl der Akkuzellen getroffen, die für diese Arbeit nicht weiter untersucht wird, da sie nicht Bestandteil der Bachelorarbeit ist. Es werden [Name der Akkuzellen] in einer 2S1P-Konfiguration verwendet, mit einer Nennspannung von [Nennspannung in V] und einer Kapazität von [Kapazität in mAh] pro Zelle. Im Folgenden wird eine grobe Berechnung der Laufzeit der MicroRat unter normalen Betriebsbedingungen durchgeführt, basierend auf diesen Werten.

t=(Kapazität des Akkupacks (mAh))/(Stromverbrauch (mA))=(3400mAh)/(500mA)=6,8h

Daher beträgt die voraussichtliche Laufzeit der MicroRat unter den gegebenen Bedingungen etwa 6,8 Stunden.

Die Leiterplatte der MicroRat wurde so ausgelegt, dass alle für den Betrieb erforderlichen elektronischen Komponenten auf möglichst effizientem Raum integriert sind. Der Mikrocontroller als zentrales Steuerelement befindet sich mittig auf der Platine, während sich die Motoransteuerungen seitlich – jeweils in der Nähe der entsprechenden Antriebseinheiten – befinden. Im unteren Bereich sind die Spannungsregler sowie der Anschluss für das Akkupack angeordnet, wodurch eine klare Trennung zwischen Versorgungs- und Steuerelektronik realisiert wurde. Die Sensorik, bestehend aus Infrarot- und Ultraschallsensoren, ist im vorderen Bereich der Leiterplatte platziert, um eine präzise Erfassung der Umgebung zu ermöglichen.

Die Konzeption und Umsetzung des Leiterplattendesigns erfolgte im Rahmen des vorangegangenen Studienmoduls „Projekt Steuergeräteentwicklung“ und stellt nicht den Gegenstand dieser Bachelorarbeit dar. Eine vertiefte Betrachtung der hardwareseitigen Auslegung ist daher nicht Bestandteil dieser Arbeit.

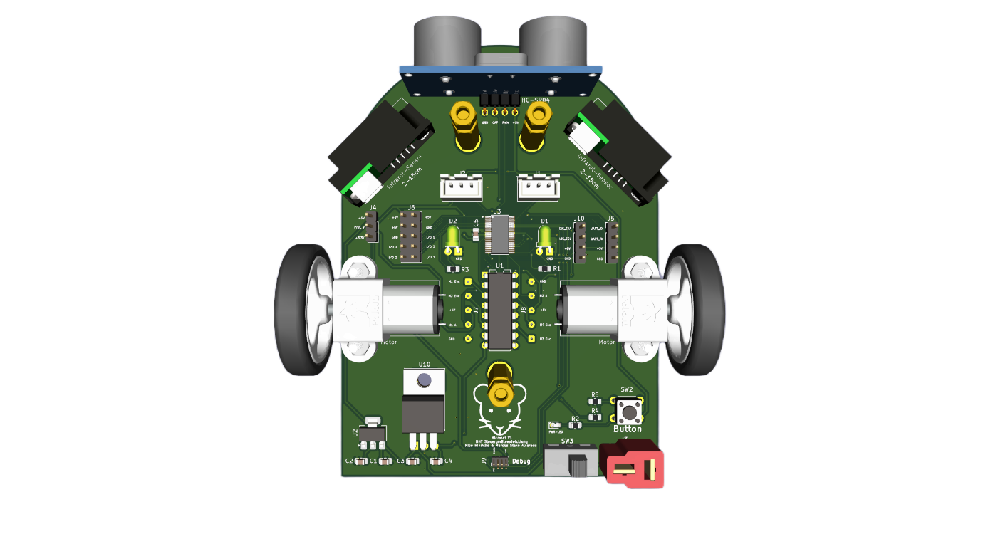
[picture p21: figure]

## 2.2 Labyrinthumgebungen

Labyrinthartige Umgebungen sind ein wesentlicher Bestandteil des Micromouse-Wettbewerbs und stellen autonome Roboter vor spezifische Herausforderungen. In solchen Umgebungen müssen Roboter ihre Fähigkeit zur selbständigen Navigation und Pfadfindung unter Beweis stellen [Quelle]. In den folgenden Abschnitten wird zunächst erläutert, was im Kontext des Micromouse-Wettbewerbs unter einem „Labyrinth“ zu verstehen ist, bevor auf die damit verbundenen Herausforderungen für die Navigation eingegangen wird.

### 2.2.1 Struktur und Definition

Ein klassisches Micromouse-Labyrinth basiert auf einem quadratischen Raster aus 16×16 Zellen. Jede Zelle besitzt eine Kantenlänge von 180 mm. Die trennenden Wände sind 50 mm hoch und 12 mm dick, wobei die nutzbare Passage zwischen zwei gegenüberliegenden Wänden 168 mm beträgt. Die Startposition befindet sich in einer der vier Ecken und ist durch drei Wände begrenzt. Das Ziel liegt im Zentrum des Labyrinths und besteht aus einem 2×2-Zellen großen Bereich [Quelle].

Die Gestaltung des Labyrinths ist in den offiziellen Richtlinien klar definiert. So sind die Seitenwände weiß und die Oberseiten rot lackiert, während der Boden aus schwarzem, nicht glänzendem Holz besteht. Diese Farbgebung unterstützt die Sensorik, insbesondere die Erkennung mittels Infrarot. Weiterhin schreiben die Richtlinien maximale Toleranzen bei der Fertigung vor, etwa bei Höhenversätzen (max. 0,5 mm) und Neigungsänderungen (max. 4°) [1].

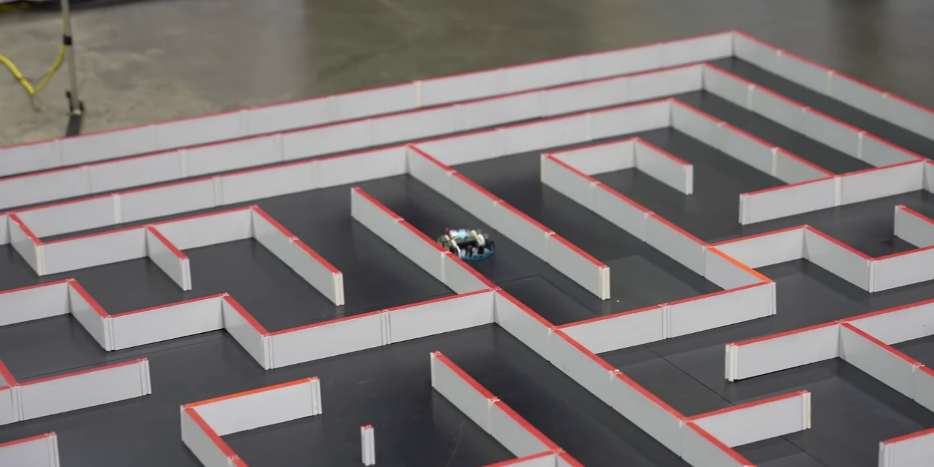
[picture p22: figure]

Das im Rahmen dieses Projekts verwendete Labyrinth orientiert sich konzeptionell an dieser Struktur, wurde jedoch hinsichtlich Abmessungen, Materialien und Ausführung an die Projektanforderungen angepasst.

### 2.2.2 Herausforderungen für Navigation

Die Navigation in labyrinthartigen Umgebungen stellt autonome Roboter vor vielfältige Herausforderungen, die sowohl die Umwelterkennung als auch die Positionsbestimmung betreffen. Eine der zentralen Hürden ist die Erkennung und Interpretation der Labyrinthstruktur. Die Umgebung ist in der Regel durch enge Passagewege und sich wiederholende Strukturen gekennzeichnet, was eine präzise Detektion der Wände, Kreuzungen und Abbiegungen erschwert. Diese Strukturen müssen zuverlässig identifiziert werden, um eine fehlerfreie Navigation zu gewährleisten. Die verwendeten Sensoren, insbesondere Infrarot- und Ultraschallsensoren, müssen nicht nur exakt kalibriert, sondern auch optimal positioniert werden, da die Reflexionseigenschaften von Oberflächen und die geringe Auflösung der Sensoren in engen Umgebungen zu fehlerhaften Messwerten führen können. In der Micromouse-Plattform kommen deshalb mehrere Infrarotsensoren im 45°-Winkel sowie ein Ultraschallsensor zum Einsatz, um die Umgebung aus verschiedenen Perspektiven zu erfassen und die Genauigkeit der Wahrnehmung zu erhöhen [2][3].

Ein weiteres Problem ergibt sich aus den begrenzten Ressourcen der Plattform, insbesondere hinsichtlich der Rechenleistung, des Speicherplatzes und der Energieversorgung. Diese Einschränkungen erfordern eine besonders effiziente Umsetzung der Navigations- und Pfadfindungsalgorithmen. Insbesondere müssen die Algorithmen so gestaltet sein, dass sie trotz der limitierten Kapazitäten zuverlässig arbeiten. Hierbei wird die Bedeutung von Optimierung und Ressourcenmanagement deutlich, da die Durchführung komplexer Berechnungen oder die Verarbeitung umfangreicher Datenmengen in Echtzeit nicht immer möglich ist [7].

Ein weiteres zentrales Hindernis ist die Positionsbestimmung des Roboters. Die Odometrie, die über Radsensoren (Encoder) die zurückgelegte Strecke und Drehbewegungen erfasst, bietet eine wichtige Grundlage für die Lokalisierung des Roboters im Labyrinth. Jedoch können auch bei sorgfältiger Kalibrierung Messfehler und Schlupf auftreten, wodurch es zu kumulierten Abweichungen von der tatsächlichen Position kommt. Diese Fehler führen zu einer immer ungenaueren Einschätzung der Position über größere Distanzen hinweg. Um dem entgegenzuwirken, ist eine kontinuierliche Korrektur der Position erforderlich, die auf den Umgebungsdaten basiert, um die Auswirkungen der fehlerhaften Odometrie zu minimieren [4][5].

## 2.3 Pfadfindungsalgorithmen

Die Fähigkeit zur effizienten Pfadfindung stellt eine zentrale Voraussetzung für die autonome Navigation von Robotern in labyrinthartigen Umgebungen dar. Verschiedene Algorithmen wurden im Laufe der Zeit entwickelt, um dieses Problem zu lösen – von einfachen Suchverfahren bis hin zu komplexen heuristischen Ansätzen. In diesem Abschnitt werden die grundlegenden Konzepte der Pfadfindung erläutert und klassische Algorithmen vorgestellt, die sich insbesondere im Kontext von Micromouse-Anwendungen bewährt haben.

### 2.3.1 Motivation und Relevanz

Pfadfindung (engl. path planning) ist ein grundlegender Bestandteil autonomer Systeme und beschreibt die Fähigkeit, basierend auf einer gegebenen Umgebungsbeschreibung einen kollisionsfreien und möglichst optimalen Weg von einem Startpunkt zu einem Zielpunkt zu bestimmen. Dabei handelt es sich um eine zentrale Teilkompetenz innerhalb der übergeordneten Fähigkeit zur Navigation.

Wie Nehmzow [1] beschreibt, besteht Navigation in mobilen Robotersystemen aus drei grundlegenden Bausteinen: Selbstlokalisierung, Pfadplanung und Karteninterpretation bzw. -erstellung (map use und map-building). Pfadplanung steht dabei in engem Zusammenhang mit der Lokalisierung des Roboters, da sowohl die aktuelle Position als auch das Ziel im selben Referenzsystem bekannt sein müssen, um eine sinnvolle Routenberechnung zu ermöglichen. Karten dienen der Repräsentation bereits erkundeter Umgebungsteile und bilden damit die Grundlage für Navigation und Pfadplanung. Diese Karten können ganz unterschiedlich gestaltet sein – von metrischen Gitternetzen bis hin zu künstlichen neuronalen Repräsentationen.

In der Literatur wird zwischen Bewegungsplanung (motion planning) und Trajektorienplanung (trajectory planning) unterschieden. Während die Bewegungsplanung die Auswahl einer geeigneten Wegstrecke in einem konfigurierten Raum (z. B. einer Karte oder einem Labyrinth) fokussiert, beschäftigt sich die Trajektorienplanung mit der konkreten Ausführung dieser Bewegung unter Berücksichtigung physikalischer Einschränkungen wie Geschwindigkeit, Beschleunigung oder mechanischen Limitierungen des Systems [2].

Für autonome Roboter ist die Fähigkeit zur Pfadplanung entscheidend für ihre Selbstständigkeit. Ein Roboter muss nicht nur auf Veränderungen in der Umgebung reagieren können, sondern auch eigenständig Wege planen, diese gegebenenfalls anpassen und neu berechnen, wenn sich die Umgebung verändert. Besonders in dynamischen oder unbekannten Umgebungen ist eine zuverlässige Pfadfindung unerlässlich [1][4].

### 2.3.2 Klassische Algorithmen

Wall-Follower

Der sogenannte Wall-Follower-Algorithmus stellt eine der einfachsten und ältesten Navigationsstrategien für Roboter dar. Das Prinzip basiert darauf, kontinuierlich einer Wand – entweder auf der linken oder auf der rechten Seite – zu folgen, bis das Ziel erreicht wird. Der Roboter tastet dabei mithilfe von Abstandssensoren seine Umgebung ab und steuert so, dass er stets entlang der gewählten Wandseite bleibt [3].

Diese Strategie funktioniert zuverlässig in sogenannten einfach zusammenhängenden Labyrinthen, also Labyrinthen, bei denen alle Wände mit dem äußeren Rand verbunden sind. In solchen Fällen garantiert der Wall-Follower, dass das Zentrum des Labyrinths erreicht werden kann, auch wenn der gefundene Pfad nicht unbedingt optimal ist [8].

Praktische Implementierungen zeigen jedoch, dass der Wall-Follower einige wesentliche Einschränkungen aufweist. Insbesondere in Labyrinthen, die nicht einfach zusammenhängend sind oder isolierte Wände enthalten, kann es vorkommen, dass der Roboter niemals das Ziel erreicht. Darüber hinaus besitzt der Algorithmus keine Möglichkeit zur Positionsbestimmung oder zur Abschätzung des bereits zurückgelegten Wegs. Er navigiert also rein reaktiv und ohne übergeordnetes Verständnis der Labyrinthstruktur [8].

Weitere Nachteile betreffen die fehlende Abbruchbedingung: Der Roboter kann unter Umständen in Schleifen geraten und muss von außen gestoppt werden, falls keine ergänzende Logik implementiert wird. Diese Limitierungen führen dazu, dass der Wall-Follower häufig nur für erste Testläufe, einfache Labyrinthe oder die erste grobe Kartierung genutzt wird. Für eine optimale Pfadfindung oder für die Navigation in komplexeren Umgebungen werden meist leistungsfähigere Algorithmen wie Flood-Fill bevorzugt [8].

Depth-First Search

Der Depth-First Search (DFS) Algorithmus gehört zu den klassischen Suchverfahren in der Robotik und wird häufig zur systematischen Erkundung von Labyrinthen eingesetzt. Die zugrunde liegende Idee besteht darin, einen Pfad so tief wie möglich zu verfolgen, bevor zu vorherigen Entscheidungspunkten zurückgekehrt wird, um alternative Routen zu untersuchen. Dies entspricht einer rekursiven Tiefenerkundung, wie sie aus der Graphentheorie bekannt ist [9].

In der Praxis bedeutet dies, dass der Roboter bei einer Kreuzung zunächst zufällig oder nach einer festgelegten Priorität eine Richtung wählt und diesem Pfad so lange folgt, bis er auf ein Hindernis oder eine Sackgasse trifft. Anschließend kehrt er schrittweise zurück, bis ein noch nicht erkundeter Pfad zur Verfügung steht. Dieser Vorgang wird solange wiederholt, bis das Ziel – im Fall der Micromouse typischerweise das Zentrum des Labyrinths – erreicht wurde [10].

Ein wesentlicher Vorteil der DFS-Methode ist ihre Vollständigkeit: Wird sie korrekt implementiert, garantiert sie das Auffinden des Ziels, sofern ein Weg existiert. In Bezug auf die optimale Pfadwahl weist sie jedoch deutliche Schwächen auf. Da DFS alle möglichen Wege bis zur maximalen Tiefe untersucht, kann der Algorithmus deutlich länger brauchen als nötig und dabei viele unnötige Zellen besuchen. Dies führt zu Ineffizienz in Bezug auf Zeit und Energieverbrauch, insbesondere im Vergleich zu Algorithmen, die heuristische Informationen einbeziehen [9][10].

Flood Fill

Der Flood-Fill-Algorithmus ist eine bewährte Strategie zur Navigation autonomer Roboter in Labyrinthumgebungen und wird besonders häufig in Micromouse-Wettbewerben eingesetzt. Im Gegensatz zu reaktiven Verfahren wie dem Wall-Follower basiert Flood-Fill auf einer systematischen Erkundung des Labyrinths mit anschließender Pfadoptimierung. Der Algorithmus verwendet ein sogenanntes „Distanzfeld“, bei dem jeder Zelle im Labyrinth ein numerischer Wert zugewiesen wird, der die Entfernung zur Zielzelle – meist dem Zentrum – angibt. Ziel ist es, von der aktuellen Roboterposition stets der Zelle mit dem niedrigsten Wert in der Umgebung zu folgen, bis das Ziel erreicht ist [11].

Zu Beginn kennt der Roboter nur seine eigene Position – alle anderen Zellen sind mit einem maximalen Distanzwert initialisiert. Während der Erkundung aktualisiert der Roboter schrittweise das Distanzfeld basierend auf den erkannten Wänden und passt die Werte der benachbarten Zellen an. Dieser Prozess entspricht der schrittweisen „Flutung“ des Labyrinths, bei der sich die niedrigsten Distanzwerte vom Ziel ausbreiten und wie eine Welle in alle Richtungen verlaufen – daher die Bezeichnung Flood-Fill [12].

Ein entscheidender Vorteil des Flood-Fill-Ansatzes liegt in der klaren Trennung zwischen Exploration und Navigation. Während der Erkundung sammelt der Roboter gezielt Informationen über die Labyrinthstruktur und aktualisiert die Distanzwerte. Sobald das Ziel gefunden wurde, kann mithilfe der gespeicherten Distanzdaten ein effizienter Rückweg oder eine optimierte Zielanfahrt berechnet werden.

Ein Nachteil besteht darin, dass der Roboter zunächst das gesamte Labyrinth (oder zumindest große Teile davon) erkunden muss, um das Distanzfeld korrekt aufbauen zu können. Flood-Fill ist somit kein rein reaktiver Algorithmus, sondern erfordert eine Form von interner Repräsentation der Umgebung (Karte). In realen Anwendungen bedeutet dies, dass der Roboter seine Umgebung mit Hilfe von Sensoren kartieren muss, um die Positionen von Wänden und offenen Wegen zu erfassen [11][12].

# 3 Anforderungsanalyse

Um eine fundierte Lösung für die Zielsetzung dieser Bachelorarbeit zu entwickeln, ist es erforderlich, die relevanten Prozesse und Anforderungen der Zielgruppe – Studierende im fünften Semester des Bachelorstudiengangs Elektromobilität – zu analysieren. Diese verfügen in der Regel bereits über grundlegende Kenntnisse im Bereich eingebetteter Systeme sowie in der Programmierung in C, jedoch meist über begrenzte Erfahrung mit der Entwicklung von Algorithmen für autonome Systeme. Daher ist es entscheidend, ihre Bedürfnisse und Erwartungen zu berücksichtigen, um eine geeignete, praxisnahe Lernumgebung zu schaffen. Ein weiterer zentraler Aspekt ist die Evaluierung der eingesetzten Softwaretools, insbesondere des DAVE IDE, das für die Entwicklung der MicroRat-Plattform verwendet wird. Die Auswahl und Handhabung dieser Werkzeuge haben wesentlichen Einfluss auf die Benutzerfreundlichkeit und den didaktischen Nutzen des Systems. Auf Basis dieser Analyse wird der Umfang der Arbeit definiert und die konkreten Ziele des Projekts – insbesondere hinsichtlich der für die Studierenden relevanten Funktionen – klar abgesteckt. Ziel ist es, eine modular aufgebaute und technisch ausgereifte Software-Basis zu entwickeln, die es ermöglicht, eigene Algorithmen auf Grundlage definierter Schnittstellen effizient zu implementieren und zu verstehen.
Das im Rahmen dieser Arbeit entwickelte System soll künftig im Modul Autonomes Fahren und intelligente Sensoren als praxisorientierte Lernplattform eingesetzt werden.

## 3.1 Aktuelle Kenntnisse der Studierenden in der Zielgruppe

Dieser Abschnitt beleuchtet die Ausgangslage der Studierenden, für die die MicroRat-Software als Lernplattform konzipiert ist. Ziel ist es, das vorhandene Vorwissen sowie die typischen Berührungspunkte der Zielgruppe mit eingebetteten Systemen und autonomer Navigation zu analysieren. Daraus werden konkrete Anforderungen an die Software abgeleitet. Diese Analyse bildet die Grundlage für ein didaktisch geeignetes und technisch zugängliches Softwaredesign, das durch klare Modulstruktur und definierte Schnittstellen die verständliche Implementierung und Weiterentwicklung eigener Algorithmen ermöglicht.

### 3.1.1 Erforderliche Vorkenntnisse für die MicroRat-Entwicklung

Für die erfolgreiche Bearbeitung der Aufgaben rund um die MicroRat sollten die Studierenden grundlegende Kenntnisse in der Programmierung, insbesondere in der Programmiersprache C, sowie im Umgang mit eingebetteten Systemen und Elektrotechnik besitzen. Die Studierenden werden in mehreren Modulen im Studienverlauf auf diese Themen vorbereitet.

Im 2. Semester wird den Studierenden die Programmiersprache C vermittelt, die die Grundlage für die Programmierung in der DAVE IDE darstellt – einer zentralen Entwicklungsumgebung für die MicroRat-Entwicklung. Im Rahmen des Moduls Mikrocomputertechnik lernen die Studierenden die grundlegenden Bausteine eingebetteter Systeme kennen, wie etwa Timer, Interrupts und Peripheriegeräte. Diese theoretischen Grundlagen sind wichtig, um ein tiefes Verständnis für die Steuerung von Mikrocontrollern und deren Interaktion mit Hardwarekomponenten zu entwickeln.

Im 3. Semester haben Sie nun grundlegende theoretische Kenntnisse aus dem 2. Semester verinnerlicht und sind in der Lage, einfache C-Programme zu schreiben und mit Mikrocontrollern zu arbeiten. Allerdings erfordert die Anwendung dieses Wissens auf reale Systeme – insbesondere bei der Arbeit mit Sensoren und Aktuatoren sowie bei der Nutzung der DAVE IDE – oft noch zusätzliche Unterstützung. Fehlerbehebung und Debugging von realer Hardware sind häufige Herausforderungen, mit denen die Studierenden konfrontiert werden.

Im 4. Semester wird das Fach Embedded Systems eingeführt, das eine praxisnahe Auseinandersetzung mit der Entwicklung eingebetteter Systeme bietet. Die Studierenden erwerben nicht nur theoretische Grundlagen, sondern sammeln durch projektbasierte Programmierung auch erste praktische Erfahrungen im Umgang mit Mikrocontrollern, Sensorik und Aktuatorsteuerung. Damit bildet dieses Modul den entscheidenden Vorbereitungsschritt für die weiterführende Anwendung im 5. Semester, in dem die MicroRat-Plattform im Rahmen des Moduls Autonomes Fahren und intelligente Sensoren als Lern- und Entwicklungsumgebung eingesetzt wird.

Trotz der praktischen Erfahrungen mit der DAVE IDE und Mikrocontrollern im Modul Embedded Systems haben viele Studierende noch Schwierigkeiten, theoretische Konzepte und Prinzipien in die Praxis eines eingebetteten Systems zu überführen. Besonders die Umsetzung von theoretischen Modellen und Algorithmen sowie deren Integration in die Steuerung von Sensoren und Aktuatoren stellt eine große Herausforderung dar. Die modulare Softwarearchitektur der MicroRat wurde entwickelt, um diesen Übergang von Theorie zu Praxis zu erleichtern. Durch eine klar strukturierte und flexibel erweiterbare Plattform können Studierende ihre theoretischen Kenntnisse auf einer soliden Grundlage anwenden, Algorithmen effizient implementieren und die Funktionsweise des gesamten Systems nachvollziehen.

Erwartungen und Bedürfnisse der Studierenden

Aus der Perspektive der Studierenden lassen sich folgende Erwartungen und Bedürfnisse ableiten, die bei der Gestaltung der Lernumgebung berücksichtigt werden sollten:

- Ein niedriger Einstiegspunkt, der den Zusammenhang zwischen Software und Hardware verständlich erklärt und es den Studierenden ermöglicht, schnell sichtbare Ergebnisse (z. B. Bewegungen der MicroRat) zu erzielen.
- Schnelle Erfolgserlebnisse, die durch einfache, gut strukturierte Aufgaben und direkte Rückmeldungen motivieren.
- Reduzierte technische Hürden, etwa bei der Konfiguration der Entwicklungsumgebung und der Fehlerbehebung.
- Kommentierter Beispielcode und strukturierte Projektvorlagen, die eine Orientierung bieten und den Einstieg erleichtern.

### 3.1.2 Verwendete Softwaretools und Entwicklungsumgebung

Die DAVE IDE stellt das zentrale Entwicklungswerkzeug zur Programmierung und Konfiguration der MicroRat dar. Sie bietet eine integrierte Umgebung zum Schreiben, Kompilieren und Debuggen von eingebettetem Code sowie zur Konfiguration von Peripheriekomponenten. Für die Zielgruppe ist es besonders wichtig, dass die Entwicklungsumgebung eine intuitive Bedienung ermöglicht und typische Aufgaben (wie beispielsweise das Einlesen von Sensorwerten oder das Ansteuern von Motoren) mit möglichst geringem technischem Aufwand umsetzbar sind. Die erste Berührung mit der DAVE IDE erfolgt im regulären Studienverlauf typischerweise im vierten Semester, wodurch das Projekt nicht nur an vorhandene Kenntnisse anknüpft, sondern gleichzeitig einen praxisnahen Einstieg in deren Anwendung bietet. Dabei knüpft die Verwendung der DAVE IDE an die im dritten Semester gelernten Konzepte und Techniken an. Beispielsweise werden Timer oder Interrupts, die Studierende in vorherigen Kursen erlernt haben, nun als Apps in der DAVE IDE eingesetzt. Diese Komponenten, die bereits als theoretische Konzepte bekannt sind, finden hier eine praktische Anwendung und ermöglichen eine direkte Umsetzung im MicroRat-Projekt. Da die DAVE IDE den primären Zugang zur Funktionalität der MicroRat darstellt, hat sie großen Einfluss auf die Benutzererfahrung und somit auf die Anforderungen an das Gesamtsystem. Entsprechend sollte das Projekt auf eine klar strukturierte Projektvorlage, einfache Dokumentation und leicht nachvollziehbare Schnittstellen zwischen Hard- und Software abzielen.

Ein typischer Workflow an der MicroRat eines Studierenden wird mit Hilfe des folgenden UML-Diagramms erläutert.

## 3.2 Systemumfang

Im Rahmen dieser Bachelorarbeit wird ein autonomer Micromouse-Roboter auf Basis der bestehenden MicroRat-Plattform eingesetzt, um die Entwicklung und Implementierung eines effizienten Pfadfindungsalgorithmus für labyrinthartige Umgebungen zu realisieren. Neben der Algorithmik werden ausgewählte Aspekte der Sensorik, der Aktorik und der Embedded-Software behandelt, die für die Navigation im Labyrinth erforderlich sind.

Im Umfang dieser Arbeit enthalten sind:

- die Entwicklung eines lauffähigen Micromouse-Systems basierend auf der bestehenden MicroRat-Plattform zur Durchführung von Navigationsexperimenten
- die Anbindung und einfache Konfiguration grundlegender Sensorik (z. B. zur Hinderniserkennung)
- eine einfache Bewegungssteuerung (z. B. lineares Vorwärtsfahren, Drehung, Stoppen)
- die Implementierung grundlegender Navigationslogik (z. B. Wandverfolgung oder simpler Maze-Solver)
- die Bereitstellung einer strukturierten DAVE IDE-Projektvorlage mit Beispielcode und Dokumentation
- die Bereitstellung eines Git-Repositories mit allen relevanten Ressourcen für Studierende

Nicht im Umfang dieser Arbeit enthalten sind:

- die Optimierung der MicroRat für Wettbewerbe (z. B. Maze-Solving-Geschwindigkeit, Hardware-Miniaturisierung)
- die Lösung komplexer Navigations- oder Mappingprobleme (z. B. SLAM, KI-gestützte Planung)
- Die Erstellung weiterer Funktionalitäten neben der vorgesehenen Labyrinthnavigation
- Die Entwicklung eines vollständigen didaktischen Konzepts für Lehrveranstaltungen

Ziel dieser Arbeit ist es nicht, eine hochleistungsfähige Wettbewerbs-Micromouse-Software zu entwickeln, sondern eine zugängliche Softwareplattform zu schaffen, die den Studierenden einen einfachen Einstieg in die Algorithmus Programmierung im Bereich autonomes Fahren und intelligente Sensoren ermöglicht, ohne dass sie sich tief in DAVE oder die Hardware einarbeiten müssen. Die Software ist modular aufgebaut und lässt sich leicht erweitern, sodass die Studierenden eigene Funktionen integrieren und mit verschiedenen Algorithmen experimentieren können.

3.3 Akteure und Anwendungsfälle

Auf Basis der zuvor beschriebenen Zielgruppe und des geplanten Funktionsumfangs lässt sich festlegen, welche Akteure mit dem System interagieren und welche konkreten Anwendungsfälle (Use Cases) sich daraus ergeben. Die folgenden Akteure wurden identifiziert:

### 3.3.1 Studierende

Die Studierenden sind die primären Nutzer der MicroRat. Sie sollen durch praktische Aufgaben grundlegende Erfahrungen in der Programmierung eingebetteter Systeme sammeln.

Anwendungsfälle:

- Die Studierenden öffnen die DAVE IDE und laden das MicroRat-Projekt. Sie kompilieren den Code und übertragen ihn auf das MicroRat.
- Die Studierenden finden eine klare Softwarearchitektur vor, die ein Verständnis dafür bietet, wie das MicroRat-System funktioniert.
- Die Studierenden sind in der Lage, anhand vorhandener Basisfunktionen, basierend auf ihrem Wissen über Algorithmen, einen eigenen Algorithmus zu programmieren.
- Die Studierenden sind in der Lage, neue Basisfunktionen zu integrieren oder bestehende zu ändern, um neue Funktionalitäten für die MicroRat zu erstellen.

### 3.3.2 Entwicklungsumgebung DAVE DIE (Systemkomponente)

Die DAVE IDE dient als Werkzeug zur Programmierung und Konfiguration der MicroRat. Sie wird von den Studierenden verwendet, um Software zu erstellen, zu testen und zu debuggen. Sie stellt die notwendige Schnittstelle zwischen den Entwicklern (Studierenden) und der Hardware zur Verfügung.

Systeminteraktionen:

- Projektmanagement und Kompilierung: Die DAVE IDE ermöglicht das Öffnen, Bearbeiten und Kompilieren von Projekten, um den Code vor der Übertragung auf das MicroRat zu validieren.
- Software-Übertragung (Flashen): Nach der Kompilierung wird die Software einfach auf das MicroRat übertragen.
- Debugging: Die IDE bietet Werkzeuge zur Fehleranalyse und Debugging.

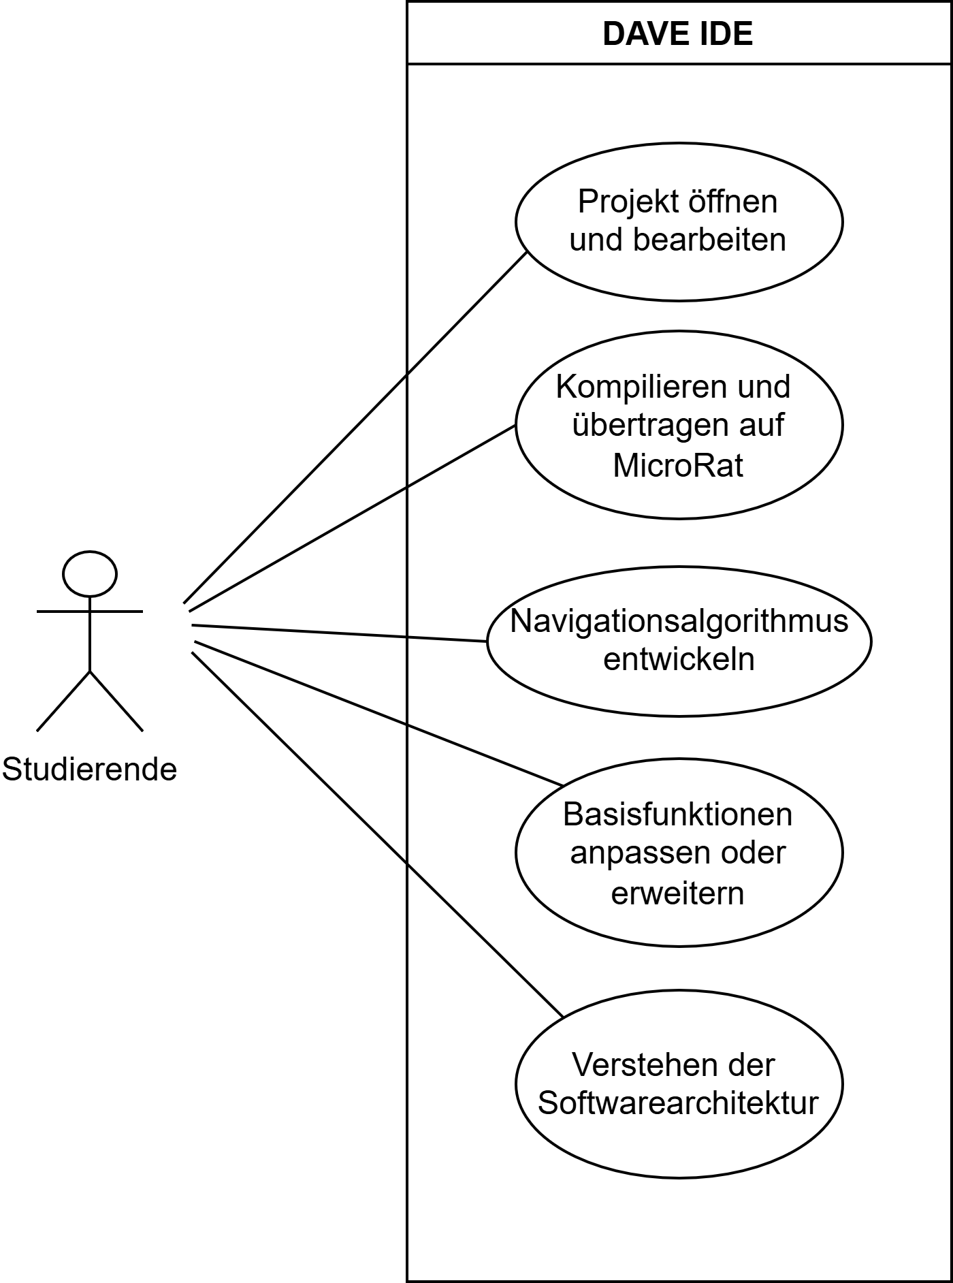
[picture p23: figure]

## 3.4 User Stories

Die folgenden User Stories beschreiben zentrale Erwartungen und Bedürfnisse der Studierenden im Umgang mit der MicroRat. Sie bilden die Grundlage zur Ableitung konkreter Anforderungen an das System und orientieren sich sowohl an typischen Lern- als auch an Nutzungsszenarien während des Semesters sowie im Rahmen von Demonstrationen. Die User Stories ergeben sich aus den zuvor definierten Use Cases und konkretisieren diese aus der Perspektive der Zielgruppe.

US#1 Als Studierender möchte ich die MicroRat mit wenig Aufwand betriebsbereit machen können, damit ich schnell mit dem praktischen Teil beginnen kann.

US#2 Als Studierender möchte ich die Softwarearchitektur der MicroRat verstehen, um zu sehen, wie die Software mit der Hardware interagiert und die Funktionalitäten wie Sensoren und Motoren steuert.

US#3 Als Studierender möchte ich mit Hilfe von Basisfunktionen eigene Algorithmen programmieren können, um zu lernen, wie Algorithmen in eingebettete Systeme implementiert werden.

US#4 Als Studierender möchte ich in der Lage sein, neue Basisfunktionen zu integrieren oder bestehende zu ändern, damit ich die MicroRat nach meinen eigenen Bedürfnissen anpassen und erweitern kann.

US#5 Als Studierender möchte ich eine klare Struktur und Kommentare im Code finden, die mir beim Verstehen der Softwarearchitektur helfen und die Implementierung eigener Funktionen erleichtern.

US#6 Als Studierender möchte ich verstehen, wie ich Sensoren und Motoren ansteuere, damit ich das Verhalten der MicroRat gezielt beeinflussen kann.

US#7 Als Studierender möchte ich Zugriff auf verständliche Dokumentation und Beispiele haben, um mich bei Problemen selbstständig orientieren zu können.

US#8 Als Studierender möchte ich auf einfache Beispielprojekte zugreifen können, die mir den Einstieg in die Programmierung der MicroRat erleichtern, damit ich sofort praktische Erfahrungen sammeln kann.

US#9 Als Studierender möchte ich kleine Anpassungen am Code vornehmen können, um unterschiedliche Szenarien mit der MicroRat auszuprobieren.

US#10 Als Studierender möchte ich verschiedene Navigationsszenarien ausprobieren können, um mein Verständnis für autonome Navigation zu vertiefen und anzuwenden.

US#11 Als Studierender möchte ich während der Vorführung einfache Statusinformationen der MicroRat erkennen können, um im Zweifelsfall reagieren oder erklären zu können, was gerade passiert.

US#12 Als Studierender möchte ich die MicroRat im Notfall sofort stoppen können, um Schäden oder Gefahren zu vermeiden.

## 3.5 Funktionale Anforderungen

Diese funktionalen Anforderungen werden aus den zuvor definierten User Stories abgeleitet und dienen als Grundlage für die anschließende Verifikation und Validierung der implementierten Funktionen.

Systemfunktionen

FA#1 Die MicroRat ermöglicht das Flashen einer Demosoftware über eine standardisierte Schnittstelle.

Begründung: Ein schneller Softwarewechsel erleichtert das Testen und die Weiterentwicklung. US#1, US#8

FA#2 Die MicroRat muss in der Lage sein, zwischen verschiedenen Navigationsstrategien wie Wandverfolgung und Labyrinth Navigation auszuwählen.

Begründung: Studierende sollen verschiedene Navigationskonzepte ausprobieren können. US#10

FA#3 Die Demosoftware läuft in der vorgesehenen Testumgebung stabil und ohne Fehlverhalten.
Begründung: Eine verlässliche Umgebung ist notwendig für das sichere Testen eigener Algorithmen. US#1, US#8

FA#4 Die MicroRat muss nach dem Einschalten zunächst auf die Betätigung des "ON"-Knopfes warten, und erst nach 5 Sekunden Wartezeit mit der Bewegung beginnen.

Begründung: Diese Verzögerung ermöglicht dem Benutzer, sich auf den Start vorzubereiten. US#1

FA#5 Die MicroRat muss in der Lage sein, eine einfache "Not-Aus"-Funktion zu unterstützen, die im Fall eines unerwarteten Fehlers oder einer Gefahr die Micromouse sofort stoppt.

Begründung: Die Funktion schützt Benutzer und Hardware im Fehlerfall. US#13

FA#6 Die MicroRat muss beim Einschalten eine Selbstdiagnose durchführen, um die Funktionsfähigkeit von Sensoren zu überprüfen.

Begründung: Frühzeitige Fehlererkennung erleichtert das Debugging. US#11, US#12

Hardwarezugriffe

FA#7 Die MicroRat muss in der Lage sein, Sensorwerte des Ultraschallsensors auszulesen.
Begründung: Ohne diese Fähigkeit kann die Micromouse nicht auf Vorderwände oder Sackgassen reagieren und ihre Navigation durchführen. US#6

FA#8 Die MicroRat muss in der Lage sein, Encoder-Impulse auszulesen.
Begründung: Diese Fähigkeit ist notwendig, damit die Studierenden einfache Bewegungsbefehle programmieren und testen können. US#6

FA#9 Die MicroRat muss in der Lage sein, PWM-Signale zur Steuerung von Motoren auszugeben.

Begründung: Eine differenzierte Geschwindigkeitsregelung ist essenziell für kontrollierte Bewegungen. US#6

FA#10 Die MicroRat muss in der Lage sein, Sensorwerte der Infrarotsensoren auszulesen. Begründung: Die IR-Sensoren dienen zur Wandverfolgung und ermöglichen die Erkennung von Seitenwänden. US#6

FA#11 Die MicroRat muss eine UART-Schnittstelle zur Verfügung stellen, die es ermöglicht, während des Betriebs Sensorwerte auszugeben.

Begründung: Eine serielle Ausgabe vereinfacht das Debugging und das Verständnis von Systemzuständen. US#6

Softwarearchitektur

FA#12 Die Softwarearchitektur muss in klar getrennte Module gegliedert sein, sodass einzelne Komponenten unabhängig voneinander geändert oder erweitert werden können.

Begründung: Eine modulare Struktur unterstützt die Erweiterbarkeit und fördert das Verständnis der Systemlogik. US#2

FA#13 Die Softwarearchitektur muss eine einfache Beispielanwendung als didaktischen Einstieg besitzen.

Begründung: Ein konkretes Beispiel erleichtert Einsteigern den Zugang zur Programmierung der MicroRat. US#8

FA#14 Die Softwarearchitektur muss eine klare Trennung zwischen der Hardwareabstraktion und der Anwendungslogik gewährleisten.

Begründung: Dadurch wird der Fokus mehr auf die Algorithmus Programmierung gesetzt. US#2

Navigation

FA#15 Die MicroRat muss in der Lage sein, mindestens 1m in einer geraden Linie ohne seitliches Abweichen zu fahren, wenn der Vorwärtsbefehl erteilt wird.
Begründung: Die MicroRat in der Lage sein, sich auf einer geraden Linie zu bewegen und dabei Kollisionen mit den Seitenwänden zu vermeiden. US#9, US#10

FA#16 Die MicroRat muss in der Lage sein, einen festen Winkel von 90° zu drehen mit einer Toleranz von +/-5°, wenn der Drehbefehl gegeben wird (im Uhrzeigersinn und gegen den Uhrzeigersinn).
Begründung: Das Drehen ist eine grundlegende Bewegung, die für die Navigation und das Testen von Programmlogiken in praktischen Szenarien erforderlich ist. US#9, US#10

FA#17 Die MicroRat muss innerhalb von 100ms nach dem Stoppen-Befehl vollständig zum Stillstand kommen.
Begründung: Ein schneller und zuverlässiger Stopp ist erforderlich, um die Sicherheit des Roboters während der Ausführung von Bewegungsbefehlen zu gewährleisten und die Kontrolle über die MicroRat zu ermöglichen. US#9, US#10, US#13

FA#18 Die MicroRat muss in der Lage sein, einen festen Winkel von 180° zu drehen mit einer Toleranz von +/-5°, wenn der Drehbefehl gegeben wird (im Uhrzeigersinn und gegen den Uhrzeigersinn).
Begründung: Diese Funktion ist erforderlich, um der Micromouse die Fähigkeit zu geben, sich in engen Umgebungen, wie z. B. in Labyrinthen, selbstständig zu befreien. US#9, US#10

FA#19 Die MicroRat muss in der Lage sein, autonome Verhaltensweisen wie Wandverfolgung und Labyrinth Navigation in einem Labyrinth auszuführen, dessen Gänge mindestens 25 cm breit sind und Wände senkrecht (90° ±5°) zueinanderstehen.
Begründung: Diese Anforderungen sind notwendig, um den Studierenden die Umsetzung autonomer Navigationsalgorithmen zu ermöglichen. US#9, US#10

FA#20 Die MicroRat muss bei fehlender Wandsensor-Erkennung nach 3 Sekunden in einen Freilaufmodus wechseln und zum Halten kommen.
Begründung: Fehlererkennung und eine einfache Möglichkeit zur Fehlerbehebung sind notwendig, um eine effiziente Nutzung der Micromouse und schnelles Debugging zu ermöglichen. US#13

FA#21 Die MicroRat muss in der Lage sein, Sackgassen zu erkennen und daraufhin ihre Richtung zu ändern.

Begründung: Diese Fähigkeit ist notwendig, damit die MicroRat nicht in einem Labyrinth stecken bleibt und weiterhin autonom navigieren kann. Ohne diese Funktion würde die MicroRat in einem Dead-End feststecken, was die Durchführung von Labyrinth-Navigationsalgorithmen unmöglich machen würde. US#9, US#10

FA#22 Die MicroRat muss in der Lage sein, geradeaus zu fahren, bis eine mögliche Abzweigung erkannt wird, um dann zum Halten zu kommen.dddddddddddddddddddddddddddddddd
Begründung: Diese Fähigkeit ermöglicht es der MicroRat, effizient durch gerade Streckenabschnitte zu navigieren und erst bei relevanten Kreuzungen oder Abzweigungen Entscheidungen zu treffen. Dies reduziert unnötige Richtungsänderungen und verbessert die Gesamteffizienz des Navigationsalgorithmus. US#9, US#10

FA#23 Die MicroRat muss bei einer erkannten Kreuzung entscheiden können, ob ein Richtungswechsel notwendig ist.dddddddddddddddddddddddddddddddddddddddddddddddddddddddddddddddd
Begründung: An Kreuzungen ist eine Entscheidungslogik erforderlich, um abhängig vom gewählten Algorithmus (z. B. Left-Hand-Rule, Flood-Fill) die passende Richtung zu wählen. Diese Funktion ist zentral für die erfolgreiche Navigation im Labyrinth. US#9, US#10

FA#24 Die MicroRat muss in der Lage sein, bereits besuchte Pfade zu erkennen und zu vermeiden, wenn dies durch die gewählte Strategie vorgesehen ist.
Begründung: Das Erkennen von bereits befahrenen Wegen ermöglicht effizientere Pfadsuche und ist bei Flood-Fill Algorithmus notwendig. US#9, US#10

FA#25 Die MicroRat muss in der Lage sein, den Zustand des internen Labyrinthmodells über die serielle UART-Schnittstelle auszugeben.ddddddddddddddddddddddddddddddddddddddddddd
Begründung: Um den Pfadfindungsalgorithmus zu überprüfen und zu debuggen, muss das aktuelle Verständnis des Labyrinths von außen einsehbar sein. US#11

## 3.6 Nicht-funktionale Anforderungen

Es ergeben sich folgende nicht-funktionale Anforderungen aus den User Stories:

NFA#1 Die Bedienung der MicroRat soll intuitiv und ohne umfangreiche Konfiguration möglich sein.

Begründung: Die Zielgruppe besteht aus Einsteiger, daher ist eine niedrige Einstiegshürde essenziell. US#1

NFA#2 Der Code, die Projektstruktur und die Hardwareanschlüsse sollen sauber dokumentiert und für Einsteiger verständlich kommentiert sein.

Begründung: Erleichtert selbstständiges Arbeiten, Verständnis und Fehlersuche für Studierende. US#5, US#7

NFA#3 Die MicroRat soll klein, leicht und einfach transportierbar sein, damit sie problemlos mitgenommen werden kann.

Begründung: Erhöht den praktischen Nutzen im Hochschulkontext.

NFA#4 Die MicroRat soll mindestens 30 Minuten autonom laufen können, ohne neu geladen zu werden.

Begründung: Die Laufzeit soll für Präsentationen und längere Tests ausreichen, ohne ständiges Nachladen.

# 4 Entwurf

## 4.1 Architekturprinzipien

Die Softwarearchitektur stellt bei der Entwicklung eingebetteter Systeme wie der MicroRat-Plattform eine grundlegende Voraussetzung für Stabilität, Wartbarkeit und Erweiterbarkeit dar. Ziel ist es, eine modulare und klar strukturierte Architektur zu entwerfen, die den funktionalen Anforderungen einer autonomen Navigationsplattform gerecht wird und gleichzeitig die Komplexität des Systems beherrschbar hält. Die zugrunde liegenden Architekturprinzipen orientieren sich an bewährten Konzepten aus der Embedded- und Softwaretechnik insbesondere an der Layered Architecture sowie ausgewählten SOLID-Prinzipien.

Eingebettete Systeme sind durch begrenzte Ressourcen, Echtzeitanforderungen sowie enge Kopplung von Hard- und Software charakterisiert. Eine wohlüberlegte Architektur ermöglicht die Trennung von hardwarenahen Funktionen von der Anwendungslogik, wodurch die Wartbarkeit sowie Wiederverwendbarkeit des Codes gesteigert werden können. Für die MicroRat wurde eine klare Schichtung eingeführt, die den Softwareaufbau in einzelne, voneinander unabhängige Komponenten gliedert.

Schichtenmodell der MicroRat Software

Die vorliegende Architektur orientiert sich am bewährten Layered Architecture Pattern und umfasst die folgenden Ebenen.

1. Applikationsebene

Diese oberste Schicht beinhaltet die primäre Steuerungslogik der Micromouse. Hier werden die Navigationsalgorithmen, Zustandsmodelle, Verhaltenssteuerungen und Kartografierung implementiert. Die Applikationsebene ist für die Steuerung des Ablaufs der Roboterfunktionen zuständig und trifft Entscheidungen bezüglich der Bewegungen und Reaktionen auf Sensordaten.

2. Schnittstellenebene

Die Schnittstellenebene stellt abstrahierte Funktionen bereit, die es ermöglichen, Sensordaten auszulesen und Aktoren anzusteuern, ohne dass ein Zugriff auf die Hardwarekomponenten erforderlich ist. Die Abstraktionsschicht fungiert als eine Art Trennschicht, welche die Applikation von der Hardware entkoppelt. Dies wiederum erleichtert den Austausch oder die Erweiterung von Komponenten.

3. Hardwareabstraktionsebene

Die Hardwareabstraktionsebene implementiert die hardware-nahen Funktionen zur Steuerung der Sensoren, Motoren und Kommunikation. Sie nutzt die APIs der DAVE IDE, um die Mikrocontrollerperipherie effizient zu konfigurieren und zu bedienen.

Prinzipien der Architekturgestaltung

Bei der Architekturgestaltung wurden bewährte Prinzipien der Softwareentwicklung berücksichtigt, um Wartbarkeit und Erwartbarkeit sicherzustellen.

- Single Responsibility Principle (SRP): Jedes Modul hat genau eine Verantwortlichkeit und erfüllt nur eine Aufgabe.
- Open/Closed Principle (OCP): Bestehende Module können durch neue Funktionalität erweitert werden, ohne dass ihre ursprüngliche Implementierung verändert werden muss.
- Dependency Inversion Principle (DIP): Abhängigkeiten verlaufen von abstrakten Schnittstellen zu konkreten Implementierungen, wodurch die Kopplung zwischen Modulen reduziert wird.
- Interface Segregation Principle (ISP): Funktionen sind in klar abgegrenzte Schnittstellen gegliedert, sodass jedes Modul nur mit den für ihn relevanten Schnittstellen interagieren muss.

Didaktische Überlegungen

Neben der technischen Zielsetzung wurde besonderer Wert auf die didaktische Aufbereitung gelegt. Die Architektur ist so konzipiert, dass Studierende die einzelnen Schichten separat betrachten und verstehen können. Die Software ist so modular aufgebaut, dass Studierende zunächst einfache Algorithmen wie den Wallfollower nachvollziehen können, bevor sie sich komplexeren Aufgaben wie der Kartografierung und Pfadoptimierung widmen. Dieser Ansatz begünstigt einen sukzessiven Lernprozess und erleichtert die Vermittlung von Konzepten autonomer Navigation in der Praxis.

## 4.2 Zustandsmodell

Ein Zustandsmodell, das auch als endlicher Automat oder Finite State Machine (FSM) bezeichnet wird, ist ein bewährtes Konzept zur Strukturierung der Steuerungslogik in eingebetteten Systemen. Es dient dazu, das Verhalten eines Systems in klar definierte Zustände zu gliedern und den Übergang zwischen diesen Zuständen durch Ereignisse oder Bedingungen zu steuern.

Für die Realisierung der MicroRat-Plattform wurde ein FSM-Ansatz gewählt, um eine Strukturierung der Steuerung der autonomen Navigationsaufgaben zu gewährleisten. Die Verwendung einer Zustandsmaschine ermöglicht es, unterschiedliche Phasen der Robotersteuerung klar voneinander zu trennen und den Ablauf systematisch zu gestalten. So können etwa das Starten, die Erkundung des Labyrinths, das Berichten des Ergebnisses sowie die Ausführung des kürzesten Pfads als separate Zustände abgebildet werden.

Gemäß den vorliegenden Informationen soll das Zustandsmodell der MicroRat folgende zentrale Zustände umfassen:

- STATE_IDLE: Die MicroRat befindet sich im Ruhezustand und wartet auf den Startbefehl.
- STATE_EXPLORE: Die Erkundung des Labyrinths findet statt. Die MicroRat nutzt hier die Wallfollower-Strategie, um sich autonom zu bewegen und das Maze zu kartografieren.
- STATE_WAIT_REPORT: Nach Erreichen des vorgegebenen Zielpunkts wartet der Roboter auf weitere Eingaben und sendet ein Statusbericht über die UART-Schnittstelle.
- STATE_SHORTEST_PATH: In diesem Zustand führt die MicroRat den kürzesten Pfad zum Ziel aus.

Jeder Zustand definiert dabei klar abgegrenzte Aufgaben und steuert entsprechende Aktionen. Der Übergang zwischen den Zuständen erfolgt in Abhängigkeit von Ereignissen oder dem Erreichen eines bestimmten Koordinatenpunkts.

## 4.3 Bewegungslogik

Die Bewegungslogik der MicroRat-Plattform basiert auf einem gitterbasierten Bewegungsmodell, das sich an der Struktur des klassischen Micromouse-Labyrinths orientiert. Das Modell ist durch quadratische Zellen charakterisiert, die jeweils einen definierten Bewegungsraum konstituieren. Die Navigation wird demnach durch das sequenzielle Ansteuern benachbarter Zellen sowie durch Drehmanöver in 90°- oder 180°-Schritten realisiert. Dieses Konzept bildet die Grundlage für eine strukturierte und deterministische Pfadplanung und erlaubt eine einfache Umsetzung von Bewegungsbefehlen auf höherer Abstraktionsebene.

Im Rahmen der Bewegungslogik werden zentrale Befehle definiert, die als High-Level-Schnittstellen innerhalb der Anwendungslogik genutzt werden können, ohne dass Kenntnisse über hardwarenahe Details erforderlich sind.

Die Umsetzung der Bewegungsbefehle erfordert eine präzise Steuerung der Antriebseinheiten. Zu diesem Zweck kommt eine geschlossene Regelungsschleife zum Einsatz, welche die Ist-Werte kontinuierlich mit den Soll-Vorgaben vergleicht. Ein PD-Regler berechnet dabei die erforderliche Korrektur, um eine gleichmäßige und zielgerichtete Bewegung sicherzustellen. Dies ist insbesondere bei Drehmanövern und geradliniger Fahrt essenziell, um Abweichungen durch Reibung, Schlupf oder Motorunterschiede zu kompensieren.

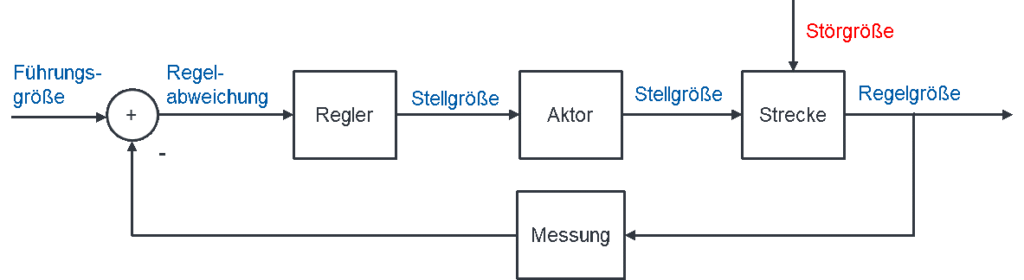
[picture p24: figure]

Die nächste Abbildung zeigt den Top-Down-Ablauf einer Bewegung innerhalb der Softwarearchitektur.

## 4.4 Sensorik-Entwurf

Die Sensorik bildet die zentrale Schnittstelle zwischen der physikalischen Umgebung und der internen Steuerlogik der MicroRat-Plattform. Das Ziel des Entwurfs besteht darin, eine abstrahierte und modulare Komponente bereitzustellen, die Umgebungsinformationen zuverlässig erfasst und in interpretierbarer Form an die Applikationsebene übermittelt.

Der Fokus liegt dabei nicht ausschließlich auf der Erfassung von Rohdaten durch Infrarot- und Ultraschallsensoren, sondern insbesondere auf deren logischer Vorverarbeitung. Anstatt die unbearbeiteten Messwerte direkt weiterzugeben, führt die Sensorik-Komponente bereits eine erste Bewertung durch, beispielsweise durch Schwellenwertbildung zur Wanddetektion. Dadurch erhält die Anwendungsebene nicht nur numerische Messgrößen, sondern semantisch interpretierbare Informationen. Ihre zentralen Aufgaben sind die periodische Datenerfassung und die regelbasierte Auswertung der Sensoreingaben. Durch wohldefinierte Schnittstellen bleibt die Komponente unabhängig von konkreten Sensortypen oder Auswertungsstrategien.

Neben dem funktionalen Beitrag zur autonomen Navigation wurde auch besonderer Wert auf die didaktische Zugänglichkeit gelegt. Der modulare Aufbau ermöglicht es Studierenden, eigene Sensorikmodule mit minimalem Aufwand zu integrieren oder bestehende Auswertelogiken zu verändern. Auf diese Weise unterstützt die Sensorik-Komponente nicht nur die Systemfunktionalität, sondern dient auch als Lernplattform zur praxisnahen Vermittlung grundlegender Konzepte eingebetteter Systeme und sensorbasierter Entscheidungslogik.

## 4.5 Maze-Datenstruktur

Im Rahmen des Softwareentwurfs bildet die Maze-Datenstruktur das zentrale Modell zur Abbildung und Verwaltung des Labyrinths, in dem sich die MicroRat bewegt. Aufgrund des gitterbasierten Aufbaus des klassischen Micromouse-Labyrinths wird das Labyrinth als zweidimensionales Raster aus Zellen modelliert. Jede Zelle entspricht dabei einem definierten Bewegungsraum, dessen Zustand bezüglich vorhandener Wände gespeichert wird.

Die Maze-Datenstruktur ist so gestaltet, dass sie Informationen über die vier möglichen Wandpositionen (Norden, Osten, Süden, Westen) einer Zelle kompakt und effizient in Form einer Bitmaske speichert. Diese Repräsentation ermöglicht eine schnelle Abfrage und einfache Aktualisierung der Wanddaten. Die Speicherung erfolgt in einer Matrix mit den Dimensionen der Labyrinthhöhe und -breite, was eine intuitive Zuordnung der physischen Labyrinthstruktur zur Softwaredarstellung sicherstellt.

Die Datenstruktur muss dynamisch aktualisiert werden können, da die MicroRat das Labyrinth im Verlauf der Navigation schrittweise erkundet. Die Aktualisierung der Wandinformationen basiert auf Sensordaten und der aktuellen Orientierung der MicroRat. Um die korrekte Zuordnung der gemessenen Wände zu den Himmelsrichtungen zu gewährleisten, wird die Ausrichtung berücksichtigt, sodass Sensorwerte in Bezug auf die globale Labyrinthrichtung interpretiert und in die Bitmaske übertragen werden.

Die zentralen Funktionen der Maze-Datenstruktur umfassen:

1. Initialisierung: Beim Start wird das Labyrinth vollständig als unerforscht markiert, indem alle Zellen auf einen Zustand ohne bekannte Wände gesetzt werden.
2. Aktualisierung: Bei jeder Positionsänderung der MicroRat werden die Wandinformationen der aktuellen Zelle entsprechend der Sensordaten und der Ausrichtung angepasst.
3. Abfrage: Zur Unterstützung der Pfadplanung können Wandinformationen zwischen benachbarten Zellen abgefragt werden. Dabei wird eine symmetrische Prüfung durchgeführt, sodass eine Wand sowohl von der einen als auch von der gegenüberliegenden Zelle erkannt wird.
4. Visualisierung: Zur externen Darstellung und Analyse werden die Labyrinthdaten über UART ausgegeben, wobei neben den Wandinformationen auch weitere Informationen wie Distanzwerte ergänzt werden können.

Dieses Design stellt sicher, dass die Maze-Datenstruktur sowohl eine kompakte Speicherung als auch eine flexible und konsistente Aktualisierung der Labyrinthdaten ermöglicht.

0,0

y

x

6,3

## 4.6 Entwurf der Algorithmen

Im Rahmen der Softwareentwicklung für die autonome Navigation der MicroRat werden zwei zentrale Algorithmen konzipiert, deren Einsatz sich an unterschiedlichen Phasen der Labyrintherkundung orientiert: die Wallfollower-Strategie sowie der Flood-Fill-Algorithmus.

Die Wallfollower-Strategie stellt eine bewährte und einfach realisierbare Methode dar, um ein unbekanntes Labyrinth systematisch zu erkunden. Hierbei folgt der Roboter konsequent einer der beiden Seitenwände — entweder links oder rechts — und nutzt diese als Orientierungshilfe zur schrittweisen Kartierung der Umgebung. Aufgrund ihrer Robustheit gegenüber unvollständigen oder temporär fehlerhaften Sensordaten eignet sich diese Strategie insbesondere für die Initialphase der Labyrintherkundung.

Im Anschluss an die Erfassung der Labyrinthstruktur wird der Flood-Fill-Algorithmus angewandt. Basierend auf den durch die Wallfollower-Strategie gewonnenen Informationen erstellt dieser Algorithmus eine Distanzkarte, welche die minimalen Distanzen von allen zugänglichen Zellen zum definierten Zielpunkt repräsentiert. Diese Karte ermöglicht eine effiziente Pfadplanung und -optimierung, indem sie dem Roboter die Navigation entlang kürzester Wege ermöglicht.

Die Kombination der beiden Algorithmen gewährleistet eine strukturierte Vorgehensweise: Zunächst erfolgt die Erkundung des unbekannten Labyrinths, gefolgt von einer gezielten und optimierten Bewegungsführung.

### 4.6.1 Wallfollower-Strategie

Die Wallfollower-Strategie ist ein klassischer Algorithmus zur Labyrintherkundung, bei dem der Roboter einer Wand entweder auf der linken oder rechten Seite konsequent folgt. Dabei nutzt die MicroRat ihre Sensorik, um Hindernisse in unmittelbarer Nähe zu detektieren und orientiert sich so an der gewählten Seitenwand, um sich sicher und systematisch durch das Labyrinth zu bewegen.

Diese Methode zeichnet sich durch ihre Einfachheit und Zuverlässigkeit aus und erlaubt es, das Labyrinth vollständig zu durchqueren, sofern es zusammenhängend ist und keine isolierten Bereiche enthält. Durch die konsequente Nutzung der Wand als Referenz wird zudem eine stabile Orientierung gewährleistet, was insbesondere in der Anfangsphase der Erkundung von Vorteil ist.

Im Rahmen des Softwareentwurfs der MicroRat ist vorgesehen, die Wallfollower-Strategie sowohl als Linksfollower als auch als Rechtsfollower implementieren zu können. Die Entscheidung, welche Seite als Referenzwand genutzt wird, kann dabei als Konfigurationsparameter festgelegt werden. Die Bewegungsentscheidungen basieren auf der kontinuierlichen Auswertung der Sensordaten, die lediglich die Anwesenheit oder Abwesenheit einer Wand detektieren, um entsprechend zu entscheiden, ob geradeaus gefahren, abgebogen oder gewartet wird.

Zu beachten ist, dass die Wallfollower-Strategie nicht notwendigerweise den kürzesten Weg zum Ziel garantiert, sondern primär auf einer systematischen Erkundung mittels Wandkontakt beruht. Diese Einschränkung ist im Entwurf berücksichtigt und wird durch die anschließende Anwendung effizienterer Algorithmen, wie dem Flood-Fill-Algorithmus, kompensiert. Die Wallfollower-Strategie dient somit als Grundlage zur initialen Labyrintherkundung und liefert die für weiterführende Pfadfindungsalgorithmen erforderlichen Wandinformationen.

Im Folgenden werden zwei unterschiedliche Szenarien dargestellt: Eines, in dem die Wallfollower-Strategie erfolgreich das Zentrum des Labyrinths findet, und ein weiteres, in dem die Strategie aufgrund der Labyrinthstruktur nicht zum Ziel führt. Diese Beispiele verdeutlichen die Grenzen der Wallfollower-Strategie als Initialmethode zur Erkundung.

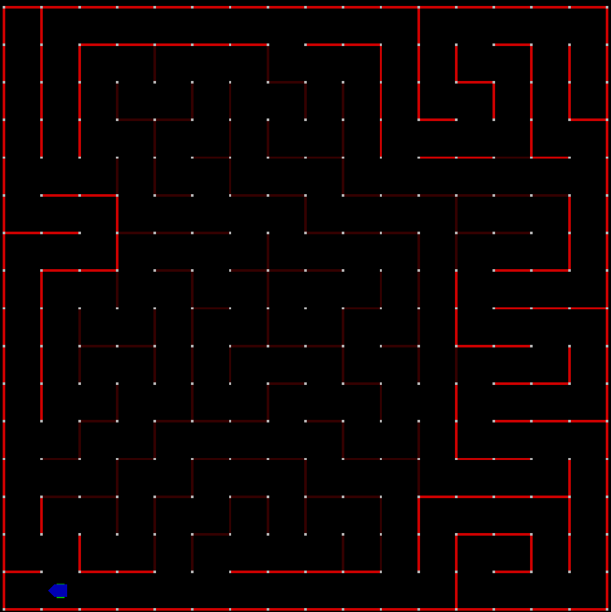
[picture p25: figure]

### 4.6.2 Flood-Fill-Algorithmus

Die Flood-Fill-Strategie ist ein verbreiteter und effizienter Algorithmus zur Labyrintherkundung und Pfadplanung in Micromouse, der auf einer schrittweisen Berechnung der Distanzwerte zu einem Zielpunkt basiert. Im Gegensatz zur Wallfollower-Strategie zielt Flood-Fill darauf ab, systematisch den kürzesten Weg zum Ziel zu ermitteln, indem jedem Feld im Labyrinth eine sogenannte Distanzzahl zugewiesen wird, welche die minimalen Schritte bis zum Ziel angibt.

Der Algorithmus arbeitet mit einer internen Repräsentation des Labyrinths als Gitter, wobei jeder Zelle ein Distanzwert zugeordnet wird. Beginnend vom Zielpunkt wird die Umgebung sukzessive mit Distanzwerten „gefüllt“ (englisch: flood fill), indem die Distanzwerte der benachbarten Zellen inkrementiert und aktualisiert werden. Dieses Verfahren führt zu einer sogenannten Distanzkarte, die den kürzesten Weg vom Startpunkt zum Ziel eindeutig festlegt.

Die MicroRat nutzt die Flood-Fill-Strategie, um nach der initialen Erkundung, zB. mittels Wallfollower, eine präzise Navigation durch das Labyrinth zu ermöglichen. Dabei wird zunächst das Labyrinth kartiert, die Wände erkannt und in einer internen Datenstruktur gespeichert. Anschließend erfolgt die Distanzzuweisung beginnend von der definierten Zielposition, welche nicht zwingend der Labyrinthmittelpunkt sein muss, sondern konfigurierbar ist.

Auf Basis der so erstellten Distanzkarte trifft die MicroRat ihre Bewegungsentscheidungen, indem sie sich immer in Richtung der Nachbarzelle mit dem geringsten Distanzwert bewegt. Dies garantiert, dass der Roboter effizient und zuverlässig den kürzesten Weg zum Ziel findet. Abbildung X zeigt die Anwendung des Flood-Fill-Algorithmus auf das von der MicroRat verwendete Labyrinth-Design. Anhand der in jeder Zelle dargestellten Distanzwerte lässt sich der kürzeste Pfad zum Ziel visuell nachvollziehen.

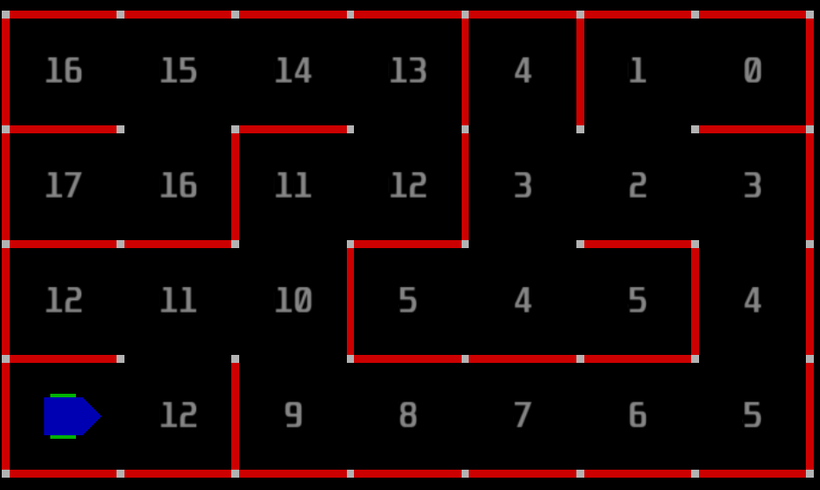
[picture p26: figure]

## 4.7 Schnittstellenübersicht

## 4.8 Debuggingkonzept

Im Rahmen des Softwareentwurfs der MicroRat wurde ein Konzept zur Unterstützung des Debuggings entwickelt, das insbesondere die Visualisierung der erkundeten Labyrinthkarte sowie der berechneten Distanzwerte vorsieht. Ziel ist es, dem Bediener eine einfache und intuitive Möglichkeit zu bieten, den internen Zustand des Roboters nachvollziehen zu können.

Geplant ist, die, während der Labyrintherkundung erfassten Wandinformationen und die Distanzwerte des Flood-Fill-Algorithmus über eine Schnittstelle in ein externes Tool zu exportieren. Dieses Tool, realisiert als Python-Skript, soll die Karte visuell darstellen und somit den aktuellen Kenntnisstand der MicroRat über das Labyrinth abbilden. Die Darstellung der Distanzwerte macht nachvollziehbar, wie der Flood-Fill-Algorithmus die kürzesten Wege zum Ziel berechnet und die Navigation steuert.

Die Implementierung dieses Debugging-Tools ist für eine spätere Entwicklungsphase vorgesehen und soll nach Abschluss der initialen Softwarekomponenten erfolgen. Zur Veranschaulichung wird im Anhang ein Beispielbild präsentiert, das zeigt, wie das ausgegebene Labyrinth inklusive erkannter Wände und Distanzwerte des Flood-Fill-Algorithmus visualisiert werden könnte.

o---o---o---o---o---o---o---o

|16 15 14 13 | 4 | 1 0 |

o---o o---o o o o---o

|17 16 |11 12 | 3 2 3 |

o---o---o o---o o---o o

|12 11 10 | 5 4 5 | 4 |

o---o o o---o---o---o o

|13 12 | 9 8 7 6 5 |

o---o---o---o---o---o---o---o

# 5 Entwicklung

Dieser Abschnitt beleuchtet die praktische Umsetzung der in Kapitel 4 entworfenen Softwarearchitektur und Algorithmen für die MicroRat-Plattform. Es wird detailliert beschrieben, welche Entwicklungsumgebungen und Werkzeuge zum Einsatz kamen und wie die einzelnen Softwarekomponenten – von der Architektur über die Bewegungssteuerung und Sensorik bis hin zu den Pfadfindungsalgorithmen und dem Visualisierungstool – implementiert wurden. Der Fokus liegt dabei auf den technischen Entscheidungen und der konkreten Realisierung der zuvor definierten Konzepte.

## 5.1 Software-Umgebung und Werkzeuge

Die Entwicklung der Software für die MicroRat-Plattform erfolgte in einer spezialisierten Embedded-Software-Umgebung, die auf die Anforderungen des verwendeten Mikrocontrollers zugeschnitten ist. Als zentrale Integrierte Entwicklungsumgebung (IDE) kam die DAVE IDE zum Einsatz, welche speziell für die Mikrocontroller der Infineon XMC-Familie optimiert ist. Die DAVE IDE basiert auf Eclipse und bietet eine umfassende Entwicklungsumgebung, die von der Projektverwaltung über den Code-Editor und Debugging-Funktionen reicht.

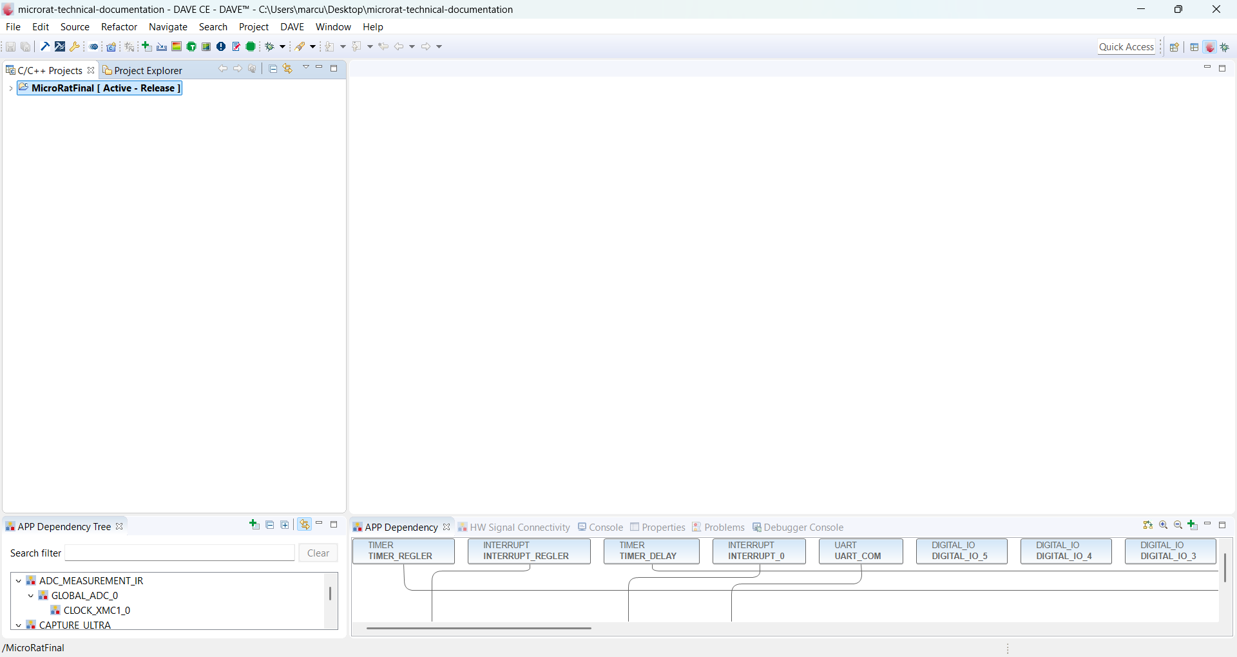
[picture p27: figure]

Für die Kompilierung des Quellcodes wurde die GNU ARM Embedded Toolchain verwendet, die den GNU C-Compiler sowie weitere Hilfsprogramme für die ARM-Architektur bereitstellt. Die primäre Programmiersprache für die Firmware der MicroRat ist C.

Für das Flashen der Firmware auf den Mikrocontroller und das hardwarenahe Debugging wurde ein J-Link Debugger eingesetzt. Die Versionsverwaltung des gesamten Softwareprojekts erfolgte mittels Git. Zusätzlich wurden die spezifischen Low-Level-Treiber und Middleware-Komponenten, die von der DAVE IDE generiert werden, für den effizienten Zugriff auf die Peripherie des Mikrocontrollers genutzt.

Ein separater Teil der Software, der MazeVisualiser, wurde in Python implementiert. Für die Entwicklung dieses Skripts kam die Visual Studio Code (VS-Code)-IDE zum Einsatz, welche Bibliotheken wie pyserial für die serielle Kommunikation nutzt. Dieses externe Tool dient der Visualisierung von Labyrinthdaten und wird in Abschnitt 5.7 detaillierter beschrieben.

## 5.2 Umsetzung der Architektur

Die Implementierung der MicroRat-Software basiert konsequent auf den in Abschnitt 4.1 definierten Architekturprinzipien und dem Schichtenmodell. Eine konsequente Trennung der Verantwortlichkeiten und die Abstraktion von Hardware-Details waren hierbei leitende Entwurfsziele, die auch in der C-basierten Entwicklung realisiert wurden.

Die dreistufige Schichtenarchitektur (Applikations-, Funktionsschnittstellen- und Hardwaresteuerungsebene) wurde durch eine entsprechende Verzeichnisstruktur im Projekt abgebildet. Dies gewährleistete eine klare Gliederung des Quellcodes und die Definition von Schnittstellen über Header-Dateien, die Funktionsprototypen und Datenstrukturen enthalten. Die im Projekt genutzte Ordnerstruktur ist in Abbildung 5.X dargestellt:

## 5.3 Bewegungssteuerung

Die Implementierung der Bewegungssteuerung ist entscheidend für die präzise und zuverlässige autonome Navigation der MicroRat. Basierend auf dem in Abschnitt 4.3 dargestellten Entwurf umfasst die Realisierung dieses Moduls die Ansteuerung der Gleichstrommotoren, die Erfassung von Odometriedaten mittels Encoder und die Implementierung eines Regelkreises zur Erreichung definierter Fahrprofile.

Das Modul movement.c/.h in der Funktionsschnittstellen/-Ebene kapselt die übergeordnete Bewegungslogik und bietet der Applikationsebene Funktionen wie MoveOneCell() zum Vorwärtsfahren um eine Zelle und Turn(TurnDirection direction) für Drehungen. Diese Funktionen übersetzen abstrakte Bewegungsbefehle in spezifische Zielvorgaben für die Antriebsmotoren.

Im Kern der Bewegungssteuerung liegt der PID-Regler, implementiert im Modul pid_regler.c/.h. Dieser Regler dient dazu, die Drehzahl und somit die Fortbewegung des Roboters präzise zu steuern. Er arbeitet in einem geschlossenen Regelkreis, wobei die aktuellen Motorumdrehungen über Inkremental-Encoder erfasst werden. Die umgerechneten Distanzwerte der Encoder werden durch das sensors.c/.h-Modul bereitgestellt und als Millimeter-Werte an den Regler übergeben.

Die korrekte Erfassung der Fahrtrichtung für die Regelung erfordert die interne Führung einer vorzeichenbehafteten Position (signed_current_pos_L/R) für jedes Rad. Da die Encoder absolute, nur inkrementelle Werte liefern, wird die Richtung der Bewegung (vorwärts/rückwärts) aus dem aktuellen Fahrziel abgeleitet. Diese vorzeichenbehaftete Position ermöglicht eine einheitliche Fehlerberechnung und präzise Regelung sowohl für Vorwärts- als auch für Rückwärtsbewegungen, indem das System den Soll-Ist-Abgleich über den gesamten Bewegungsbereich durchführt. Die zentrale Logik des PID-Reglers, welche in der UpdatePID()-Funktion periodisch, alle 1 ms, durch ein Timer-Interrupt aufgerufen wird, berechnet die erforderlichen PWM-Werte für die Motoren basierend auf dem aktuellen Fehler, dessen Integration über die Zeit und dessen Änderungsrate.

Die berechneten PWM-Signale werden anschließend dem Motoransteuerungsmodul (hal_motor.c/.h) zugeführt, welches daraus die entsprechenden elektrischen Signale generiert, um die H-Brücke anzusteuern. Diese regelt wiederum die Stromzufuhr und somit die Drehzahl sowie Drehrichtung der Motoren. Eine typische PWM-Frequenz von 2,5 kHz wurde gewählt. Die PIDdone()-Funktion überprüft die Erreichung des Ziels durch eine Toleranzschwelle für die Fehlerwerte beider Räder und eine minimale Anzahl stabiler Zyklen, um ein Überschwingen zu verhindern.

Bei der Implementierung und Abstimmung des PID-Reglers war die Bestimmung geeigneter Reglerparameter (Kp, Ki, Kd) eine zentrale Aufgabe. Diese Parameter wurden iterativ durch Tests auf der realen Hardware kalibriert, um ein Über- oder Unterschwingen zu vermeiden. Zusätzlich wurden richtungsabhängige Kalibrierungsfaktoren für die PWM-Werte (z.B. PWM_L_FORWARD_FACTOR) eingesetzt, um Asymmetrien im Antriebssystem auszugleichen und die Präzision weiter zu erhöhen.

## 5.4 Sensorik

Für die Umfelderfassung und autonome Navigation der MicroRat ist eine zuverlässige Sensorik unerlässlich. Die Implementierung gliedert sich in die Ansteuerung und Auswertung verschiedener Sensortypen. Während die hardwarenahe Steuerung in Modulen der Hardwaresteuerungsebene (hal_ir.c/.h, hal_us.c/.h, hal_encoder.c/.h) erfolgt, werden die Daten in der Funktionsschnittstellen-Ebene im Modul sensors.c/.h zusammengeführt, verarbeitet und der Applikationsebene bereitgestellt.

Ein Überblick über die wichtigsten Funktionen des sensors.c/.h-Moduls, die der Applikationsebene zur Verfügung stehen:

Infrarotsensoren dienen der präzisen Distanzmessung zu Wänden. Nach Erfassung der Rohwerte durch hal_ir.c/.h erfolgt im sensors.c/.h-Modul eine nicht-lineare Kalibrierung mittels Look-Up-Tabelle und linearer Interpolation (_convertIrRawToMm()). Die Funktionen GetDistanceLeft_mm() und GetDistanceRight_mm() (siehe Listing 5.3) liefern kalibrierte Distanzen in Millimetern, inklusive des mechanischen Offsets. IsWallLeft() und IsWallRight() prüfen auf Wände basierend auf einem Schwellenwert.

Der vorderseitig platzierte Ultraschallsensor dient primär der Erfassung von Distanzen nach vorne und der Erkennung von Wänden. Er ergänzt die IR-Sensorik durch seine größere Reichweite. Die hardwarenahe Ansteuerung erfolgt in hal_us.c/.h. Funktionen wie GetDistanceFront_mm() (siehe Listing 5.3) im sensors.c/.h-Modul skalieren die Rohdaten in Millimeter, während IsWallFront() (siehe Listing 5.3) eine boolesche Aussage zur Wandpräsenz liefert.

Encoder dienen als Sensoren zur Erfassung der gefahrenen Strecke der Räder. Die hardwarenahe Implementierung erfolgt in hal_encoder.c/.h. Das Modul sensors.c/.h stellt darauf aufbauend Funktionen wie GetEncoderLeft_mm() und GetEncoderRight_mm() bereit (siehe Listing 5.3), welche die rohen Encoder-Ticks mittels des Umrechnungsfaktors TICK_PER_MM in Millimeter umwandeln. Diese Distanzinformationen in Millimetern sind grundlegend für die Bewegungsregelung, da der PID-Regler direkt auf Millimeter-Werte regelt.

## 5.5 Labyrinthkartierung und -verwaltung

Die Maze-Verwaltung, implementiert im Modul maze.c/.h, ist ein fundamentaler Bestandteil der Softwarearchitektur, der die autonome Navigation der MicroRat im Labyrinth ermöglicht. Sie ist verantwortlich für die interne Repräsentation der Umgebung, die dynamische Aktualisierung dieser Karte basierend auf erfassten Sensordaten und die Bereitstellung von Informationen für die Pfadfindung sowie für übergeordnete Navigationsentscheidungen.

Das Labyrinth wird intern als zweidimensionales Gitter von Zellen abgebildet. Jede Zelle ist durch ihre X- und Y-Koordinaten eindeutig identifizierbar. Zwei globale Arrays, mazeMap und distanceMap, speichern den Zustand des Labyrinths. Das mazeMap Array speichert die Wandinformationen für jede Zelle. Jede Zelle wird als Ganzzahl repräsentiert, wobei einzelne Bits die Präsenz einer Wand in einer bestimmten Himmelsrichtung kodieren (Bit 0 für Norden, Bit 1 für Osten, Bit 2 für Süden und Bit 3 für Westen). Das distanceMap Array wird für den spätern Flood-Fill genutzt, um die Distanz von einem Zielpunkt zu jeder erreichbaren Zelle zu speichern. Die Initialisierung der mazeMap erfolgt durch die Funktion MazeMap_Init(), die alle Zellen mit dem Wert 0 versieht, was bedeutet, dass zunächst keine Wände bekannt sind.

Die Aktualisierung der Labyrinthkarte erfolgt dynamisch während der Erkundung durch die Funktion updateMazeMap(). Diese greift auf die aktuellen Sensorinformationen der IsWallFront(), IsWallLeft() und IsWallRight()-Funktionen zu. Basierend auf der aktuellen Ausrichtung des Roboters (currentOrientation, z.B. NORTH, EAST, SOUTH, WEST) werden die entsprechenden Bits in der mazeMap der aktuellen Zelle gesetzt, wenn eine Wand erkannt wird.

Das maze.c/.h-Modul stellt zudem essenzielle Funktionen bereit, die von externen Pfadfindungsalgorithmen genutzt werden, um Routen durch das Labyrinth zu planen. Die Hilfsfunktion isValidCell() überprüft, ob eine gegebene Zellenkoordinate innerhalb der gültigen Labyrinthgrenzen liegt. Die Funktion hasWallBetween() prüft, ob eine Wand zwischen zwei benachbarten Zellen vorhanden ist. Sie zeichnet sich durch eine symmetrische Prüfung aus: Es wird sowohl die entsprechende Wand in der Startzelle als auch die Gegenwand in der Zielzelle überprüft. Dies gewährleistet eine robuste und konsistente Erkennung von Durchgängen, unabhängig von der Blickrichtung des Roboters bei der initialen Erkundung.

Für Entwicklungs- und Debugging-Zwecke bietet das Modul die Funktion printMazeMap(). Diese sendet die aktuelle mazeMap und distanceMap über die UART-Schnittstelle, formatiert als [Y][X]:MAZE_MAP_VALUE:DISTANCE_MAP_VALUE,.

## 5.6 Implementierung der Pfadfindungsalgorithmen

Die Navigation der MicroRat im Labyrinth basiert auf der Implementierung von zwei grundlegenden Pfadfindungsalgorithmen: dem Wallfollower-Algorithmus für die Erkundung und einem Flood-Fill-Algorithmus zur Berechnung des kürzesten Weges. Beide Algorithmen sind im Modul pathfinding.c/.h implementiert und nutzen die von der Labyrinthkartierung und -verwaltung bereitgestellten Informationen.
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

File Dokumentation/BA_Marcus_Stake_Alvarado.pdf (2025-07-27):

# Entwicklung und Implementierung eines effizienten

vorgelegt am: 30.06.2025; Matrikelnummer: 929605

Pfadfindungsalgorithmus für autonome Micromouse-
Roboter in labyrinthartigen Umgebungen

Zwölfwöchige Abschlussarbeit im Rahmen der Prüfung

im Bachelorstudiengang Elektromobilität

an der Berliner Hochschule für Technik

von: Marcus Stake Alvarado

1. Betreuer: Prof. Dipl.-Ing. Koshan Mahdi

2. Gutachter: Prof. Dr. Sven Graupner.

Berliner Hochschule für Technik

## Vorwort

Diese Bachelorarbeit wäre ohne die Unterstützung von Prof. Dipl.-Ing. Koshan Mahdi und Prof. Dr.

Sven Graupner nicht möglich gewesen. Ich danke Ihnen herzlich für ihre fachliche Begleitung, die

wertvollen Anregungen und das entgegengebrachte Vertrauen während der gesamten Bearbeitungszeit.

Mein Dank gilt auch Frank Stenzel für seine tatkräftige Unterstützung, insbesondere beim Aufbau des

Projekts.
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

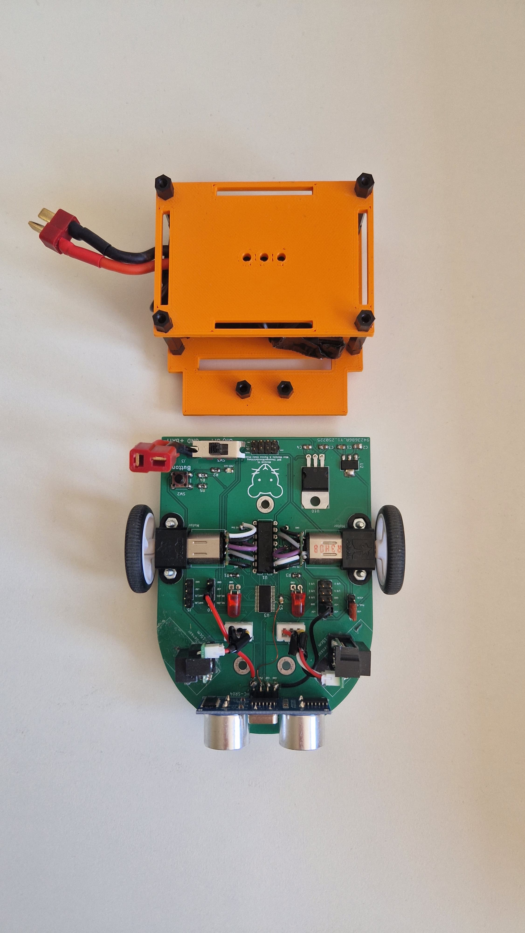
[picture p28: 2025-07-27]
Bilder & Videos/Bilder/MicroRatTop_seperat.jpg

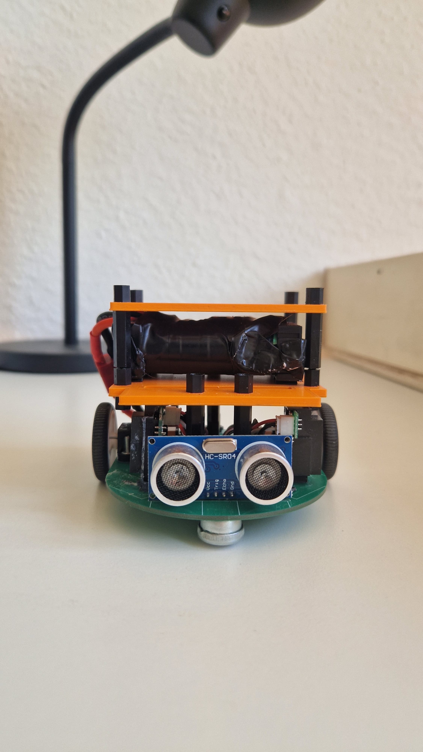
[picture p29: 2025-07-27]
Bilder & Videos/Bilder/MicroRatFront.jpg

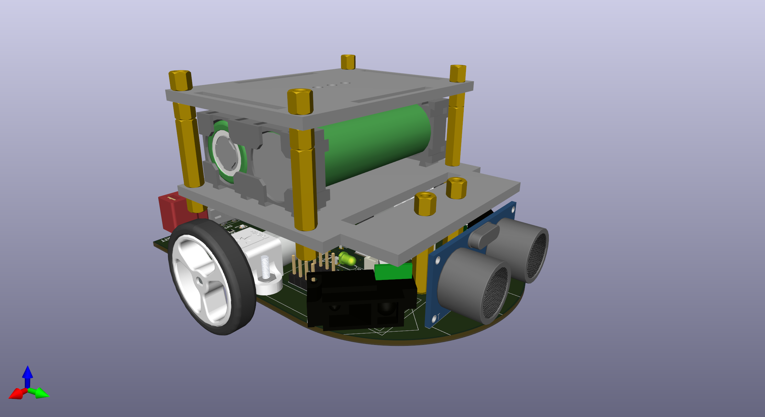
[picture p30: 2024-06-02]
Bilder & Videos/Bilder/Microrat3.png

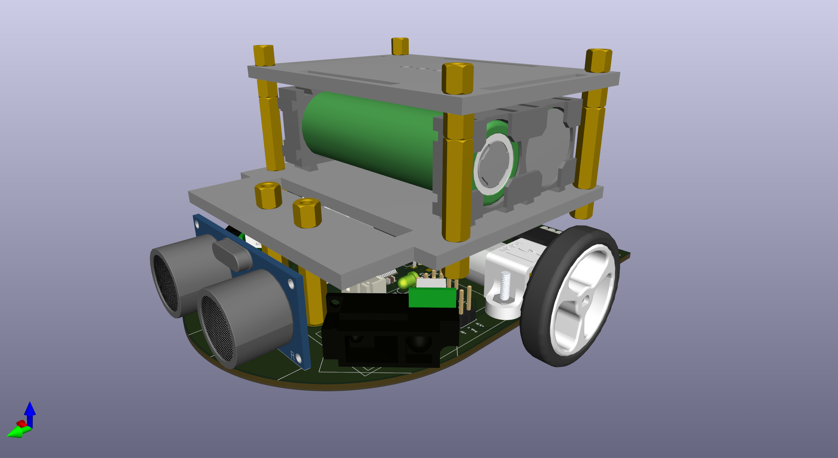
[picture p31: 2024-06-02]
Bilder & Videos/Bilder/Microrat1.png

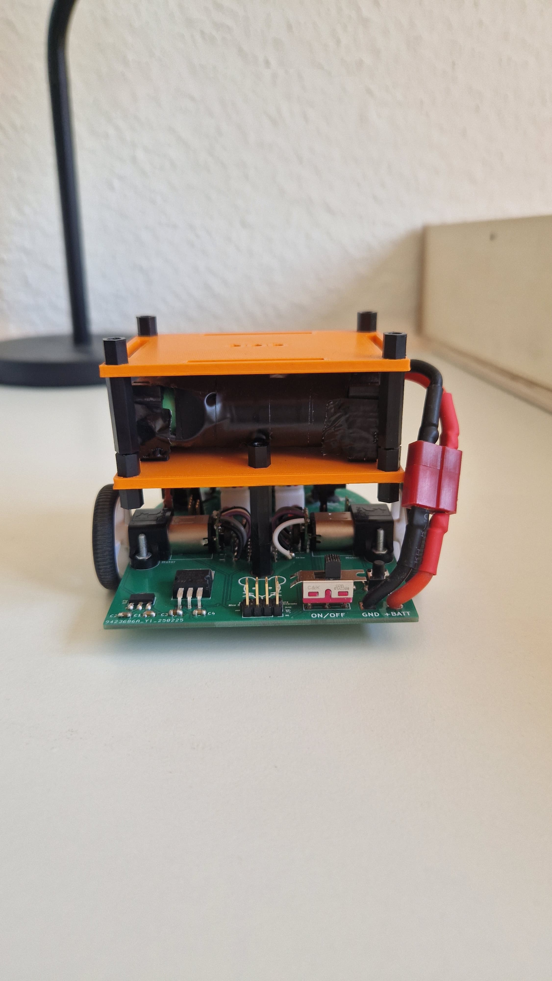
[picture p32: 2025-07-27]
Bilder & Videos/Bilder/MicroRatHinten.jpg

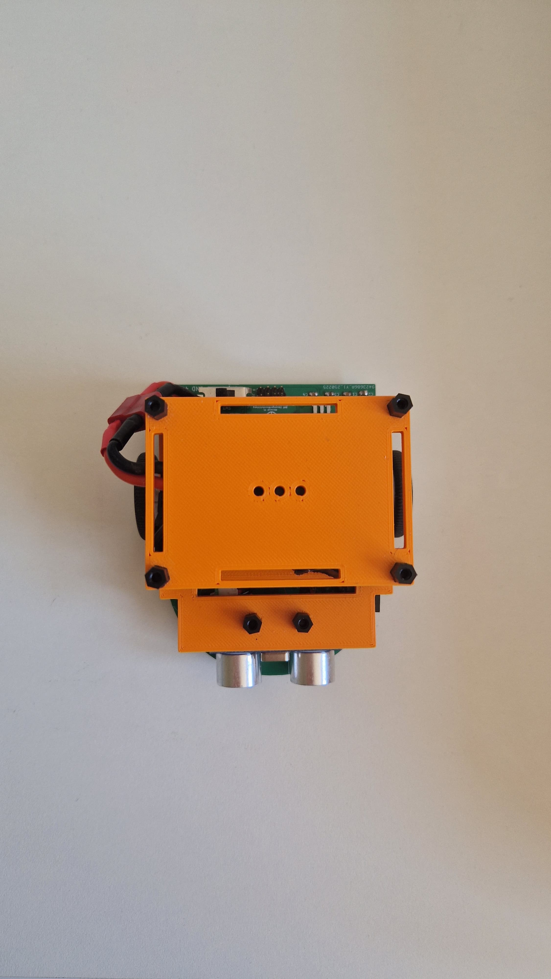
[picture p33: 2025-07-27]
Bilder & Videos/Bilder/MicroRatTop.jpg

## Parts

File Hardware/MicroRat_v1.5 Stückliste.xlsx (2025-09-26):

Begriff | Bauteilnummer | Bauteilbezeichnung | Menge | Anbieter | Kosten pro Stück | Link
Li-Ion Zelle | beliebig | beliebig, muss aber Nennspannung 3,6V haben | 2 | / | / | /
Micro Motor | PO1093 | 50:1 Micro Metal Gearmotor HP 6V with 12 CPR Encoder, Side Connector | 2 | Pololu | 25.65 € | https://pololu.com (https://www.pololu.com/product/5161)
Dual H-Brücke | L293D | Zündungscontroller und Treiber Push-Pull 4-Channel | 1 | Mouser | 7.54 € | https://www.mouser.de (https://www.mouser.de/ProductDetail/STMicroelectronics/L293D?qs=gr8Zi5OG3MgMJ1ICDzLQbg%3D%3D)
Spannungsregler Motoren | L7806 | L7806CV STM Spannungsregler, fest, +6 V, 1,5A, 4%, TO-220 | 1 | reichelt | 0.35 € | https://www.reichelt.de (https://www.reichelt.de/de/de/spannungsregler-fest-6-v-1-5a-4-to-220-l7806cv-stm-p216573.html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)
Schalter Versorgung | 1101M1S3CQE2 | Schiebeschalter 120 V 6 A 1 x Ein/Ein | 1 | Conrad | 8.99 € | https://www.conrad.de (https://www.conrad.de/de/p/c-k-switches-1101m1s3cqe2-schiebeschalter-120-v-6-a-1-x-ein-ein-1-st-bulk-2577417.html)
Taster | COM-00097 | SparkFun Zubehör Mini Pushbutton Switch | 1 | Mouser | 0.32 € | https://www.mouser.de (https://www.mouser.de/ProductDetail/SparkFun/COM-00097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)
Ultraschallsensor | OSEPP Electronics | HC-SR04 Ultraschall Modul Entfernungsmesser Sensor | 1 | Mouser | 5.61 € | https://www.mouser.de (https://www.mouser.de/ProductDetail/OSEPP-Electronics/HC-SR04?qs=wNBL%252BABd93PqZEhuhHkuOw%3D%3D)
2-15cm IR Sensor | GP2Y0A51SK0F-K | GP2Y0A51SK0F-K Distanzsensor, 20 - 150mm, analog, inkl. Kabel | 2 | reichelt | 15.80 € | https://www.reichelt.de
Räder | PO1088 | Pololu Wheel 32x7mm Pair White for Micro Metal Gearmotors | 1 | Eckstein | 4.95 € | https://eckstein-shop.de (https://eckstein-shop.de/Pololu-Wheel-32x7mm-Pair-White-for-Micro-Metal-Gearmotors)
Status LEDs | 150060GS75000 | Standard-LEDs - SMD WL-SMCW SMDMono TpVw Waterclr 0603 Green | 3 | Mouser | 0.14 € | https://www.mouser.de (https://www.mouser.de/ProductDetail/Wurth-Elektronik/150060GS75000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)
Bracket Motoren | PO989 | Pololu Micro Metal Gearmotor Bracket Pair Black for Mounting | 1 | Eckstein | 3.95 € | https://eckstein-shop.de (https://eckstein-shop.de/Pololu-Micro-Metal-Gearmotor-Bracket-Pair-Black-for-Mounting)
Mini Caster Wheel | SKU: 80041207 | Kugelrolle, 8 mm, mit Flansch | 2 | Kugelrollen-shop | 4.49 € | https://kugelrollen-shop.de (https://kugelrollen-shop.de/kugelrolle-mm-mit-flansch/80041207-p-41207.html)
T-Stecker | HSTT STBU | HSTT STBU Steckverbinder für Li-Polymer-Akkus, 2-polig, T-DEAN | 1 | reichelt | 1.49 € | https://www.reichelt.de (https://www.reichelt.de/steckverbinder-fuer-li-polymer-akkus-2-polig-t-dean-hstt-stbu-p207645.html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)
M3x20mm | 710-971200324 | Abstandsbolzen & Abstandshalter WA-SBRIE M3x20mm SW5.5 | 7 | Mouser | 1.45 € | https://www.mouser.de (https://www.mouser.de/ProductDetail/Wurth-Elektronik/971200324?qs=wr8lucFkNMXKngrP7yiDpg%3D%3D)
M3x5mm | 710-971050327 | Abstandsbolzen & Abstandshalter WA-SSSIE Spacer Stud M3x5mm SW5.5 | 11 | Mouser | 1.51 € | https://www.mouser.de (https://www.mouser.de/ProductDetail/Wurth-Elektronik/971050327?qs=wr8lucFkNMVv2fIfQ46KHw%3D%3D)
M3x5mm | 728-FM1252-3005-A | Abstandsbolzen & Abstandshalter 3.0 X 0.5 THRD ALUM FEMALE 5mm LENGTH | 7 | Mouser | 0.62 € | https://www.mouser.de (https://www.mouser.de/ProductDetail/Fascomp/FM1252-3005-A?qs=VHdrSJkwcua44KgnThhqgQ%3D%3D)
Spannungsregler PCB | LD1117S50TR | LDO Voltage Regulators 5V 0.8A Positive | 1 | Mouser | 0.40 € | https://www.mouser.de (https://www.mouser.de/ProductDetail/STMicroelectronics/LD1117S50TR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)
XMC1402 | XMC1402-T038X0128 AA | Microcontroller | 1 | Infineon | 2.50 € | https://www.infineon.com (https://www.infineon.com/part/XMC1402-T038X0128-AA)
LM7301SN1T1G | 863-LM7301SN1T1G | Operational Amplifiers - Op Amps 32V Rail-to-Rail Input & Output, 4MHz | 1 | Mouser | 0.31 € | https://www.mouser.de (https://www.mouser.de/ProductDetail/onsemi/LM7301SN1T1G?qs=tCMd4XlZ/iBtuAGHooSlQQ%3D%3D)
BSL307SP H6327 | 726-BSL307SPH6327 | MOSFETs SMALL SIGNAL+P-CH | 1 | Mouser | 0.84 € | https://www.mouser.de (https://www.mouser.de/ProductDetail/Infineon-Technologies/BSL307SP-H6327?qs=y2kkmE52mdN0GnfnIDecGQ%3D%3D)
BAT60AE6327HTSA1 | 726-BAT60AE6327HTSA1 | Schottky Diodes & Rectifiers 10 V 3000 mA | 1 | Mouser | 0.34 € | https://www.mouser.de (https://www.mouser.de/ProductDetail/Infineon-Technologies/BAT60AE6327HTSA1?qs=OwbwYO03UsIW3Y2lCXbs8Q%3D%3D)

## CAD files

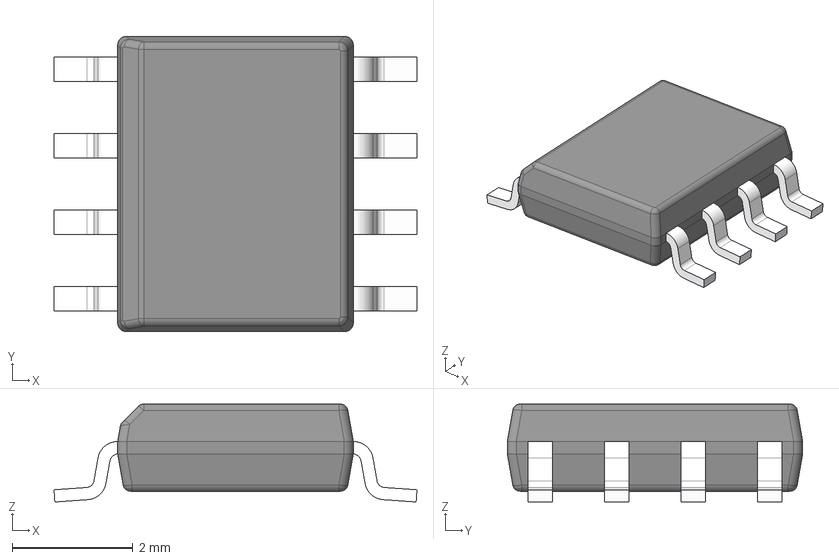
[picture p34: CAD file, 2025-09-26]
Hardware/3D Modelle/LMV358M_NOPB.stp
6.02 x 4.90 x 1.63 mm
BODY-SO
LEAD-D0008A x 8

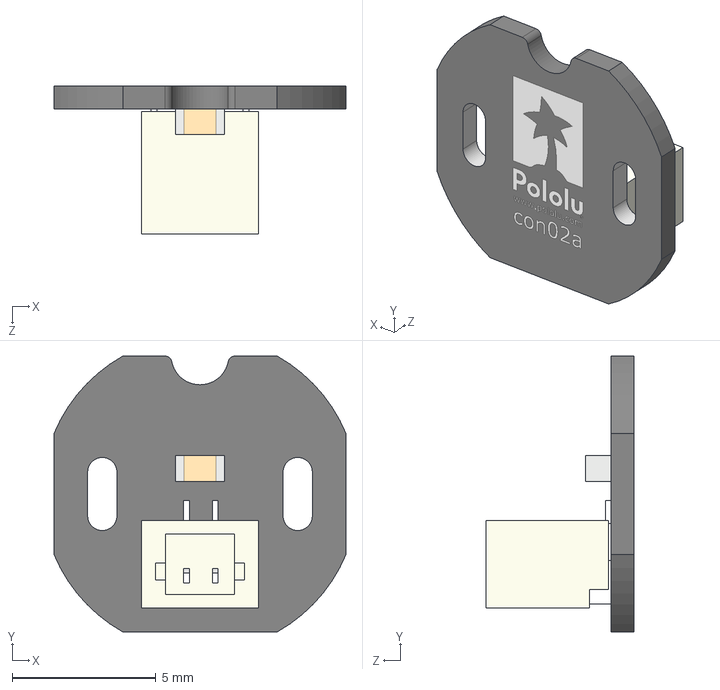
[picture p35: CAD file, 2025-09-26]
Hardware/3D Modelle/Pololu Micro Metal Gearmotor 3D Models/Accessories/jst-sh-style-connector-board-for-micro-metal-gearmotors-back-entry.step
10.2 x 9.60 x 5.14 mm

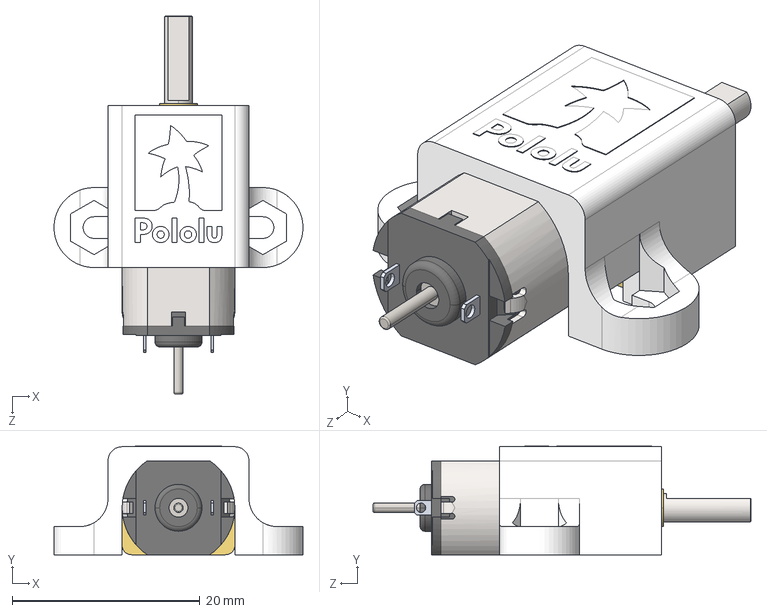
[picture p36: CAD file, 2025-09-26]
Hardware/3D Modelle/Pololu Micro Metal Gearmotor 3D Models/With Bracket/mmgm-pm-ext-shaft-with-1089-ext-bracket.step
26.5 x 11.6 x 40.2 mm

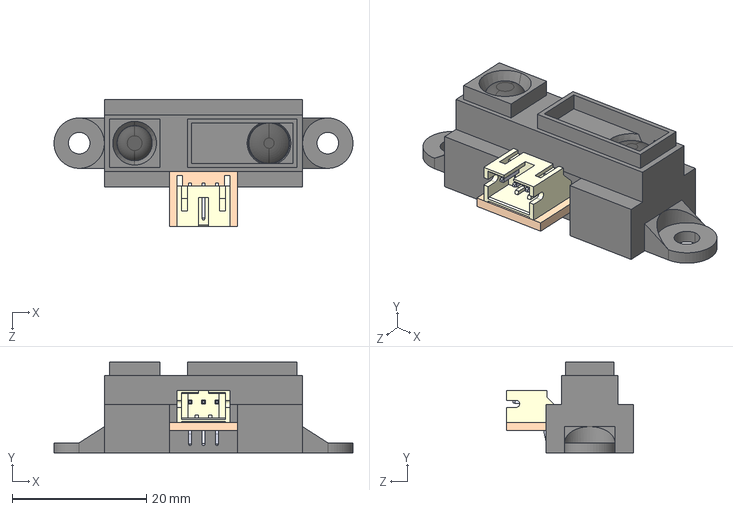
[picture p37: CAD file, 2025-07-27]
Hardware/KiCAD_Imports/GP2Y0A51SK0F/GP2Y0A51SK0F.step
44.5 x 13.5 x 18.9 mm

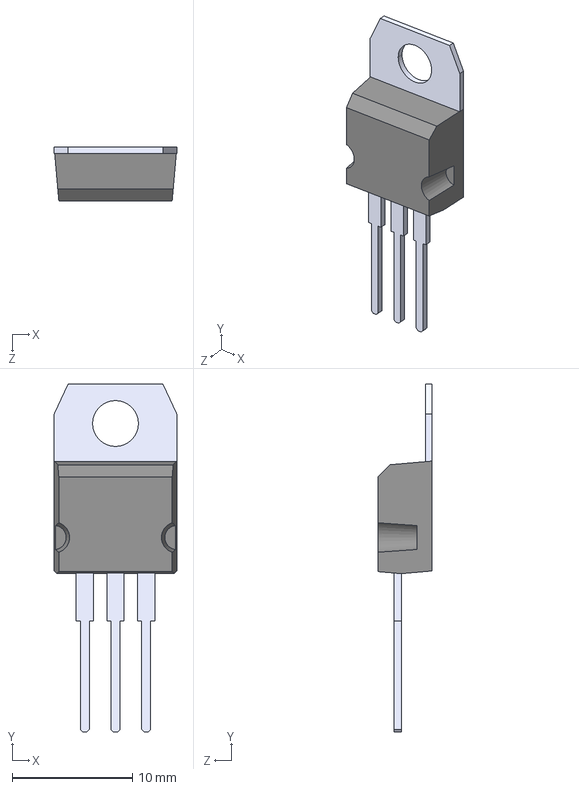
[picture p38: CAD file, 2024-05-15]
Hardware/KiCAD_Imports/L7806CV/L7806CV.step
10.2 x 28.9 x 4.50 mm

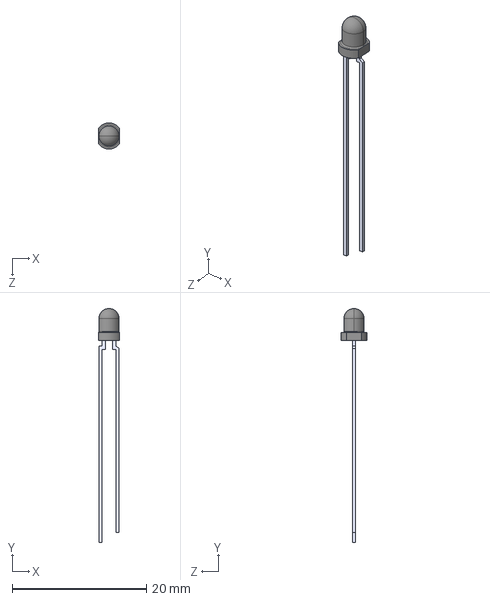
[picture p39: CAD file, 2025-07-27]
Hardware/KiCAD_Imports/TEFT4300/TEFT4300.step
3.20 x 34.9 x 3.90 mm

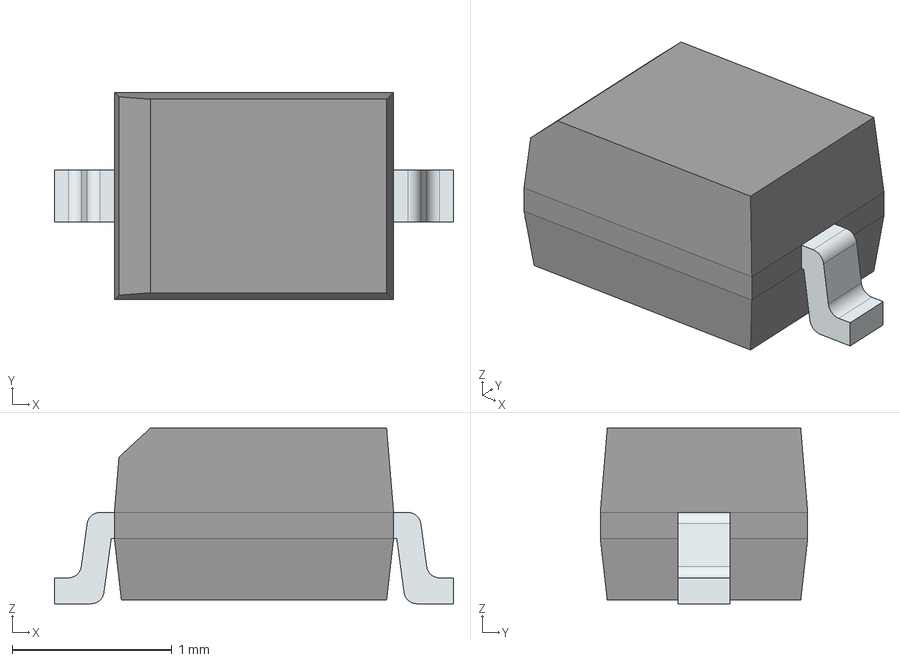
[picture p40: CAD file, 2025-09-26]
Hardware/3D Modelle/BAT60AE6327HTSA1.stp
2.50 x 1.30 x 1.10 mm
FilletPinL
FilletPinR

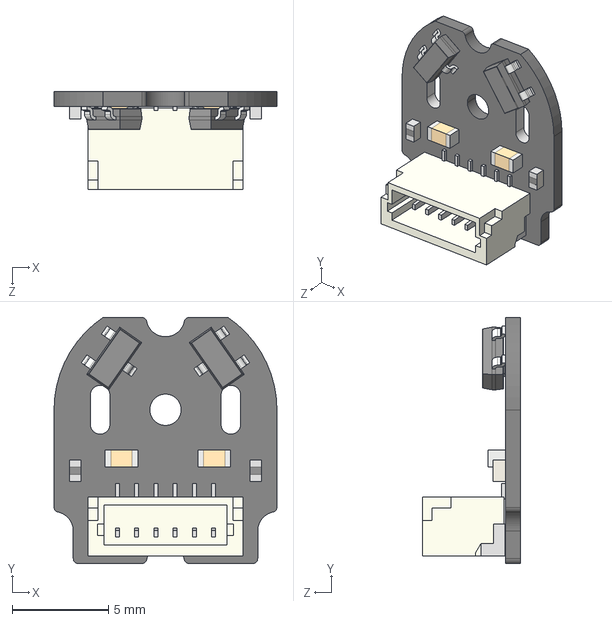
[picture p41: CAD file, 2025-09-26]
Hardware/3D Modelle/Pololu Micro Metal Gearmotor 3D Models/Accessories/magnetic-encoder-with-top-entry-connector-for-micro-metal-gearmotors.step
11.6 x 12.8 x 5.11 mm

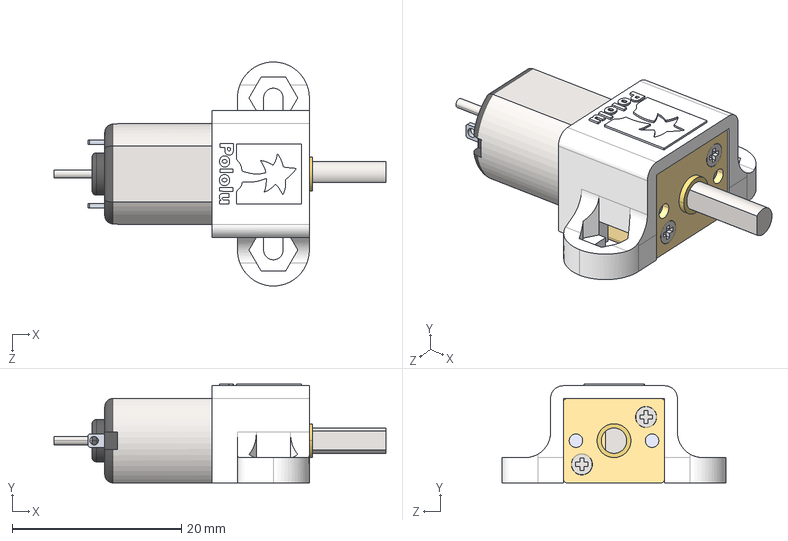
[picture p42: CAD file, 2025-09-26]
Hardware/3D Modelle/Pololu Micro Metal Gearmotor 3D Models/With Bracket/mmgm-pm-ext-shaft-with-1086-bracket.step
39.3 x 11.7 x 26.5 mm

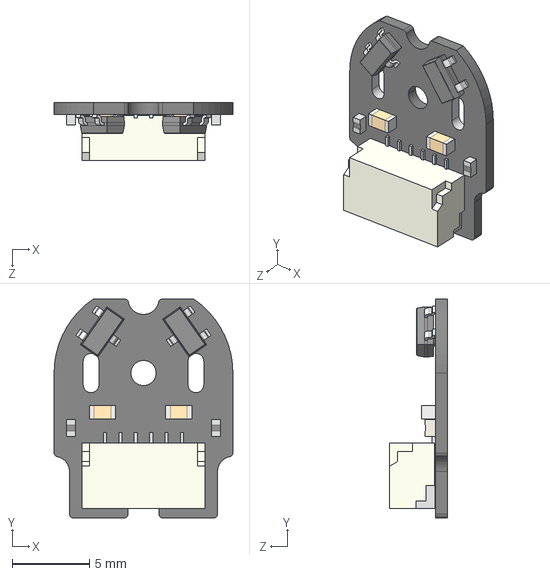
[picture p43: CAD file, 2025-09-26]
Hardware/3D Modelle/Pololu Micro Metal Gearmotor 3D Models/Accessories/magnetic-encoder-with-side-entry-connector-for-micro-metal-gearmotors.step
11.6 x 14.2 x 3.75 mm

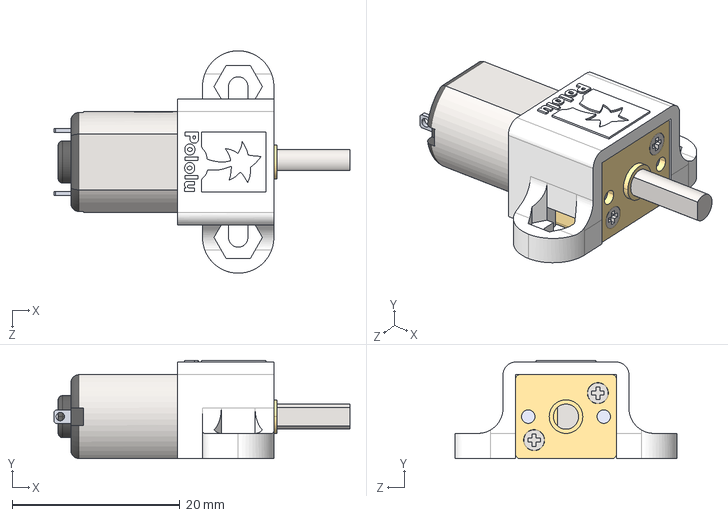
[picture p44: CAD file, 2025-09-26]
Hardware/3D Modelle/Pololu Micro Metal Gearmotor 3D Models/With Bracket/mmgm-pm-with-1086-bracket.step
35.3 x 11.7 x 26.5 mm

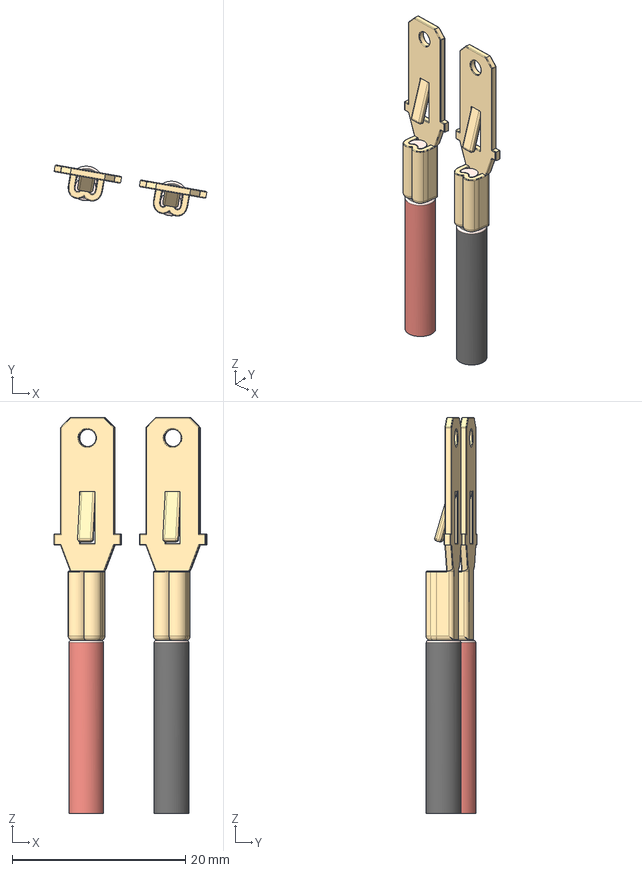
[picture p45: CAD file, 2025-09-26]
Hardware/3D Modelle/Spade Terminal 6.3mm x 24mm.step
17.6 x 5.91 x 45.8 mm
Spade 6.3mm x 24mm
Spade 6.3mm x 24mm (1)

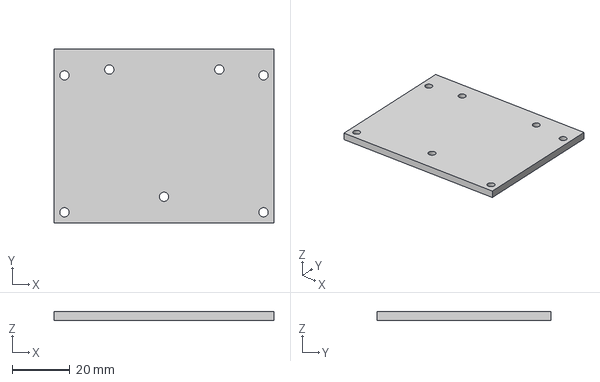
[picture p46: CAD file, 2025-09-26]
Hardware/3D Modelle/BMS Platte neu.step
76.0 x 60.1 x 3.00 mm

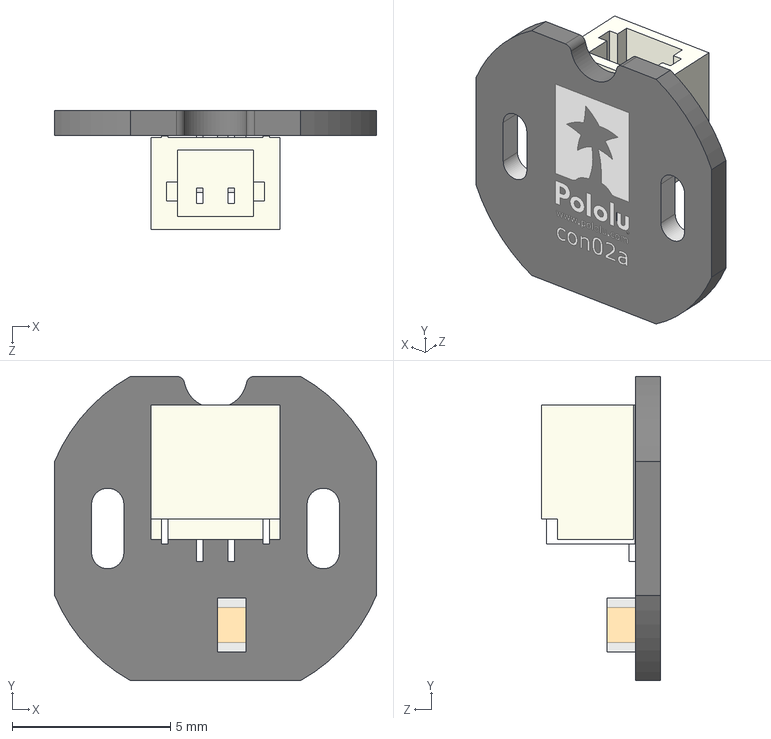
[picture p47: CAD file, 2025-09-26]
Hardware/3D Modelle/Pololu Micro Metal Gearmotor 3D Models/Accessories/jst-sh-style-connector-board-for-micro-metal-gearmotors-side-entry.step
10.2 x 9.60 x 3.75 mm

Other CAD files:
Hardware/3D Modelle/Pololu Micro Metal Gearmotor 3D Models/With Bracket/mmgm-pm-with-1089-ext-bracket.step
Hardware/3D Modelle/Pololu Micro Metal Gearmotor 3D Models/Accessories/magnetic-encoder-disc-for-micro-metal-gearmotors.step
Hardware/3D Modelle/SOT23-6.STEP
Hardware/3D Modelle/2S 7.step
Hardware/3D Modelle/1101M2S3CQE1.stp
Hardware/3D Modelle/150060GS75000.step
Hardware/3D Modelle/150060GS75000.stp
Hardware/3D Modelle/18650 Li-Ion.step
Hardware/3D Modelle/36756-HPN-2-56-A2.stp
Hardware/3D Modelle/70341-SIP-2-56-7-16-A2.stp
Hardware/3D Modelle/BMS Platte 2 v2.step
Hardware/3D Modelle/BMS Platte v4.step
Hardware/3D Modelle/Holder 2Pcs 18650 step.STEP
Hardware/3D Modelle/Kugelrolle Platzhalter v1.stl
Hardware/3D Modelle/LM7301SN1T1G.stp
Hardware/3D Modelle/M3_F_TO_F_5MM_STANDOFF.STEP
Hardware/3D Modelle/M3_M_TO_F_20MM_STANDOFF.STEP
Hardware/3D Modelle/M3_M_TO_F_5MM_STANDOFF.STEP
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

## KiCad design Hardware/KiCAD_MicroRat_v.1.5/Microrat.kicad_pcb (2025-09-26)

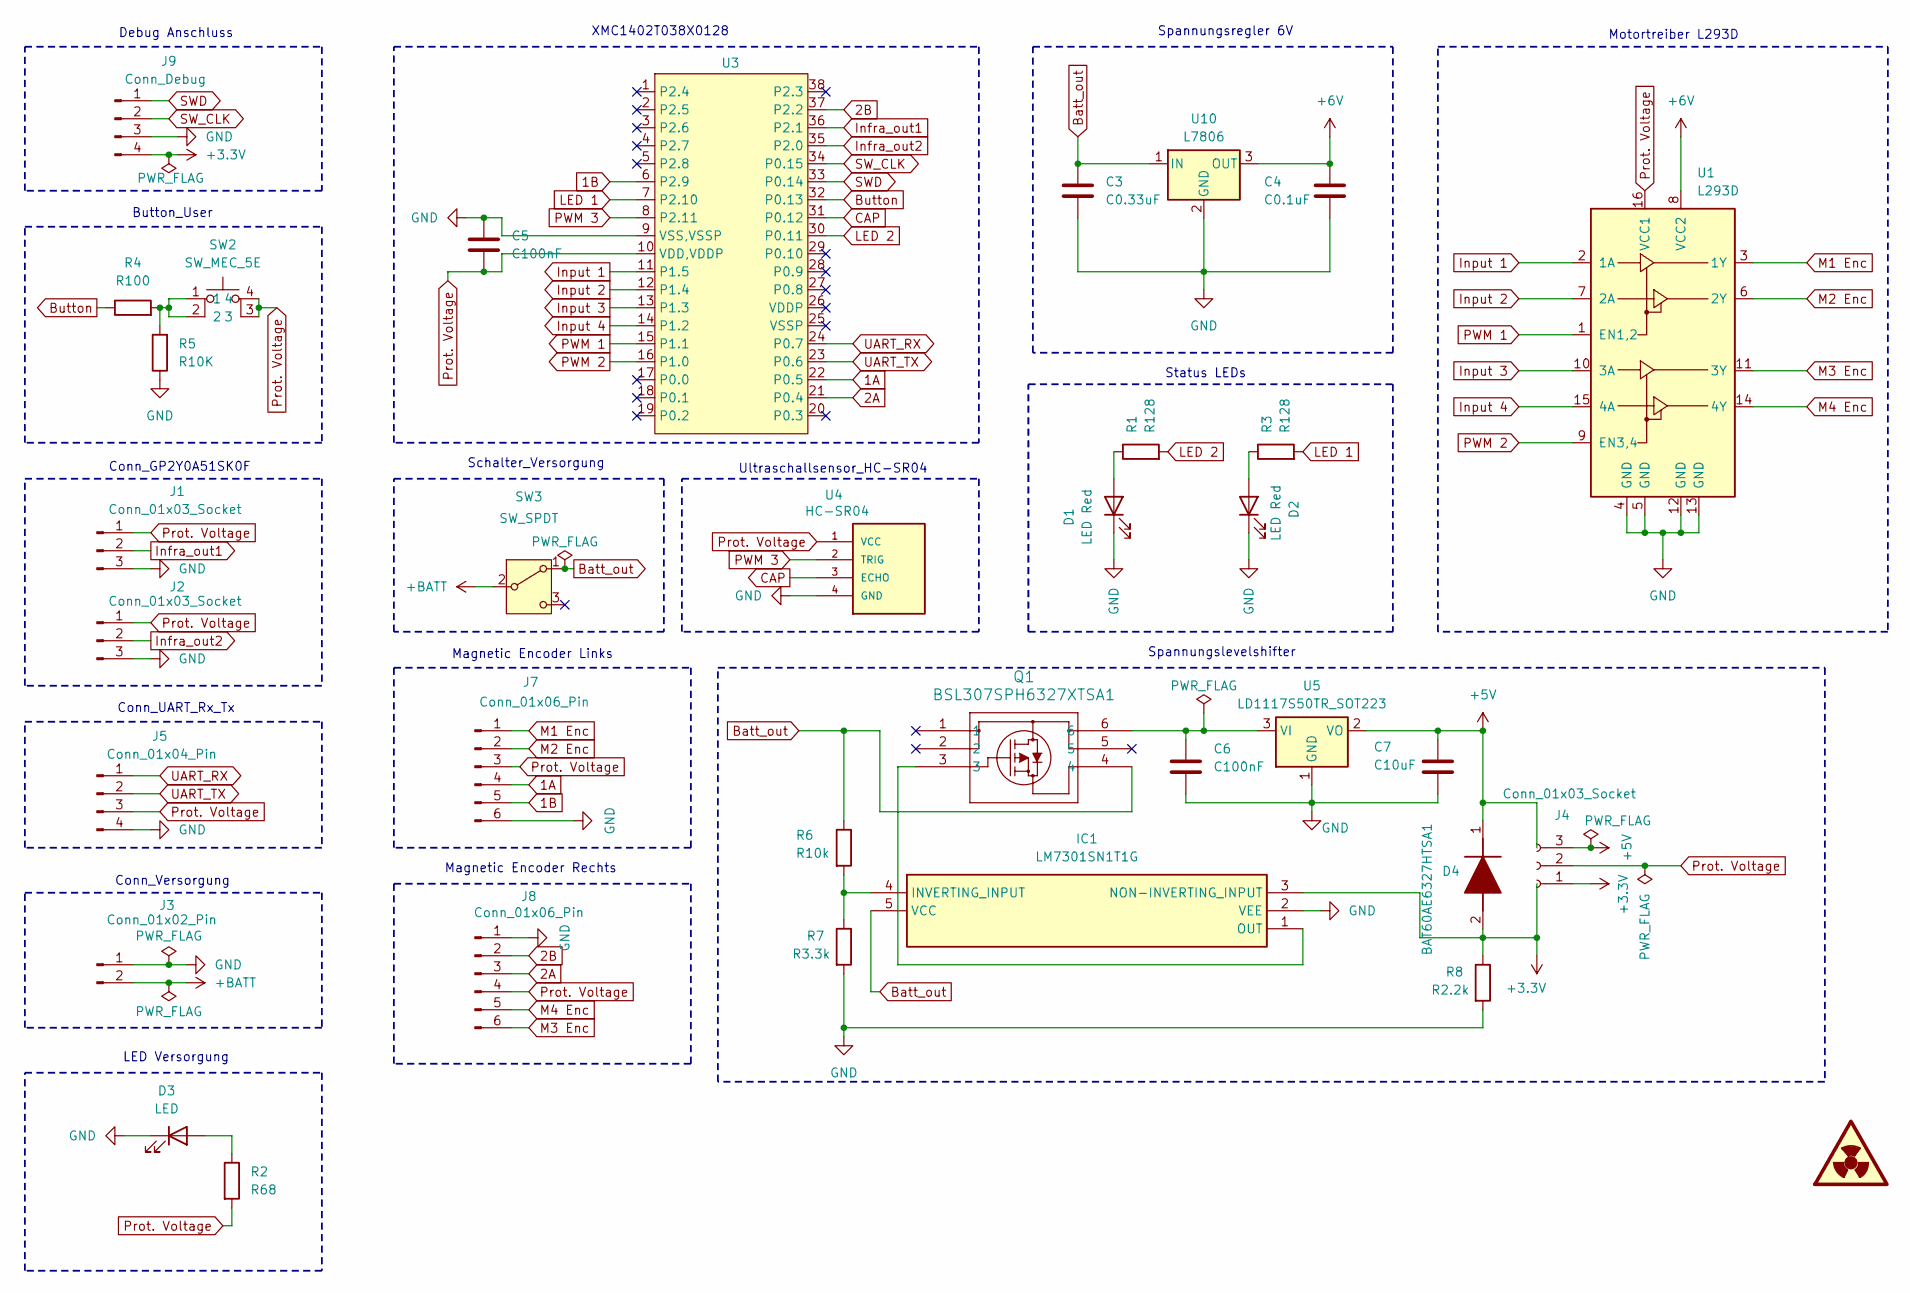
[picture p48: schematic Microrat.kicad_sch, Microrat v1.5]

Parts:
C3: C0.33uF; C_0805_2012Metric_Pad1.18x1.45mm_HandSolder
C4: C0.1uF; C_0805_2012Metric_Pad1.18x1.45mm_HandSolder
C5, C6: C100nF; C_0805_2012Metric_Pad1.18x1.45mm_HandSolder
C7: C10uF; C_0805_2012Metric_Pad1.18x1.45mm_HandSolder
D1, D2: LED Red; LEDC1608X80N
D3: LED; LEDC1608X80N
D4: BAT60AE6327HTSA1; SOD2513X110N; Mouser Part Number 726-BAT60AE6327HTSA1
IC1: LM7301SN1T1G; Manufacturer_Part_Number LM7301SN1T1G; Mouser Part Number 863-LM7301SN1T1G
J1, J2: Conn_01x03_Socket; SolderWire-0.1sqmm_1x03_P3.6mm_D0.4mm_OD1mm
J3: Conn_01x02_Pin; SolderWire-2.5sqmm_1x02_P7.2mm_D2.4mm_OD3.6mm
J4: Conn_01x03_Socket; PinHeader_1x03_P2.54mm_Vertical
J5: Conn_01x04_Pin; PinHeader_1x04_P2.54mm_Vertical
J7, J8: Conn_01x06_Pin; SolderWire-0.1sqmm_1x06_P3.6mm_D0.4mm_OD1mm
J9: Conn_Debug; PinHeader_1x04_P2.54mm_Vertical
Q1: BSL307SPH6327XTSA1; PG-TSOP-6-1_INF
R1, R3: R128; R_0805_2012Metric_Pad1.20x1.40mm_HandSolder
R2: R68; R_0805_2012Metric_Pad1.20x1.40mm_HandSolder
R4: R100; R_0805_2012Metric_Pad1.20x1.40mm_HandSolder
R5: R10K; R_0805_2012Metric_Pad1.20x1.40mm_HandSolder
R6: R10k; R_0805_2012Metric_Pad1.20x1.40mm_HandSolder
R7: R3.3k; R_0805_2012Metric_Pad1.20x1.40mm_HandSolder
R8: R2.2k; R_0805_2012Metric_Pad1.20x1.40mm_HandSolder
SW2: SW_MEC_5E; SW_PUSH_6mm_H4.3mm
SW3: SW_SPDT; Schiebeschalter
U1: L293D; DIP-16_W7.62mm
U3: SOP50P640X120-38N
U4: HC-SR04; XCVR_HC-SR04
U5: LD1117S50TR_SOT223; SOT-223-3_TabPin2
U10: L7806; TO-220-3_Horizontal_TabDown

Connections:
1A: J7.4, U3.22 (P0.5)
1B: J7.5, U3.6 (P2.9)
2A: J8.3, U3.21 (P0.4)
2B: J8.2, U3.37 (P2.2)
+3.3V: D4.2 (A), IC1.3 (NON-INVERTING_INPUT), J4.1, J9.4, R8.1
+5V: C7.1, D4.1 (K), J4.3, U5.2 (VO)
+6V: C4.1, U1.8 (VCC2), U10.3 (OUT)
+BATT: J3.2, SW3.2 (B)
Batt_out: C3.1, IC1.5 (VCC), Q1.4, R6.1, SW3.1 (A), U10.1 (IN)
Button: R4.1, U3.32 (P0.13)
CAP: U3.31 (P0.12), U4.3 (ECHO)
GND: C3.2, C4.2, C5.1, C6.2, C7.2, D1.1 (K), D2.1 (K), D3.1 (K), IC1.2 (VEE), J1.3, J2.3, J3.1, J5.4, J7.6, J8.1, J9.3, R5.1, R7.2, R8.2, U1.4 (GND), U1.5 (GND), U1.12 (GND), U1.13 (GND), U3.9 (VSS,VSSP), U4.4 (GND), U5.1 (GND), U10.2 (GND)
Infra_out1: J1.2, U3.36 (P2.1)
Infra_out2: J2.2, U3.35 (P2.0)
Input 1: U1.2 (1A), U3.11 (P1.5)
Input 2: U1.7 (2A), U3.12 (P1.4)
Input 3: U1.10 (3A), U3.13 (P1.3)
Input 4: U1.15 (4A), U3.14 (P1.2)
LED 1: R3.2, U3.7 (P2.10)
LED 2: R1.2, U3.30 (P0.11)
M1 Enc: J7.1, U1.3 (1Y)
M2 Enc: J7.2, U1.6 (2Y)
M3 Enc: J8.6, U1.11 (3Y)
M4 Enc: J8.5, U1.14 (4Y)
unnamed: D1.2 (A), R1.1
unnamed: D2.2 (A), R3.1
unnamed: D3.2 (A), R2.1
unnamed: IC1.4 (INVERTING_INPUT), R6.2, R7.1
unnamed: IC1.1 (OUT), Q1.3
unnamed: R4.2, R5.2, SW2.1, SW2.2
unnamed: C6.1, Q1.6, U5.3 (VI)
PWM 1: U1.1 (EN1,2), U3.15 (P1.1)
PWM 2: U1.9 (EN3,4), U3.16 (P1.0)
PWM 3: U3.8 (P2.11), U4.2 (TRIG)
Prot. Voltage: C5.2, J1.1, J2.1, J4.2, J5.3, J7.3, J8.4, R2.2, SW2.3, SW2.4, U1.16 (VCC1), U3.10 (VDD,VDDP), U4.1 (VCC)
SWD: J9.1, U3.33 (P0.14)
SW_CLK: J9.2, U3.34 (P0.15)
UART_RX: J5.1, U3.24 (P0.7)
UART_TX: J5.2, U3.23 (P0.6)

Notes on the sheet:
Magnetic Encoder Rechts
Spannungslevelshifter
XMC1402T038X0128
Conn_Versorgung
LED Versorgung
Status LEDs
Schalter_Versorgung
Conn_GP2Y0A51SK0F
Spannungsregler 6V
Conn_UART_Rx_Tx
Ultraschallsensor_HC-SR04
Debug Anschluss
Magnetic Encoder Links
Button_User
Motortreiber L293D

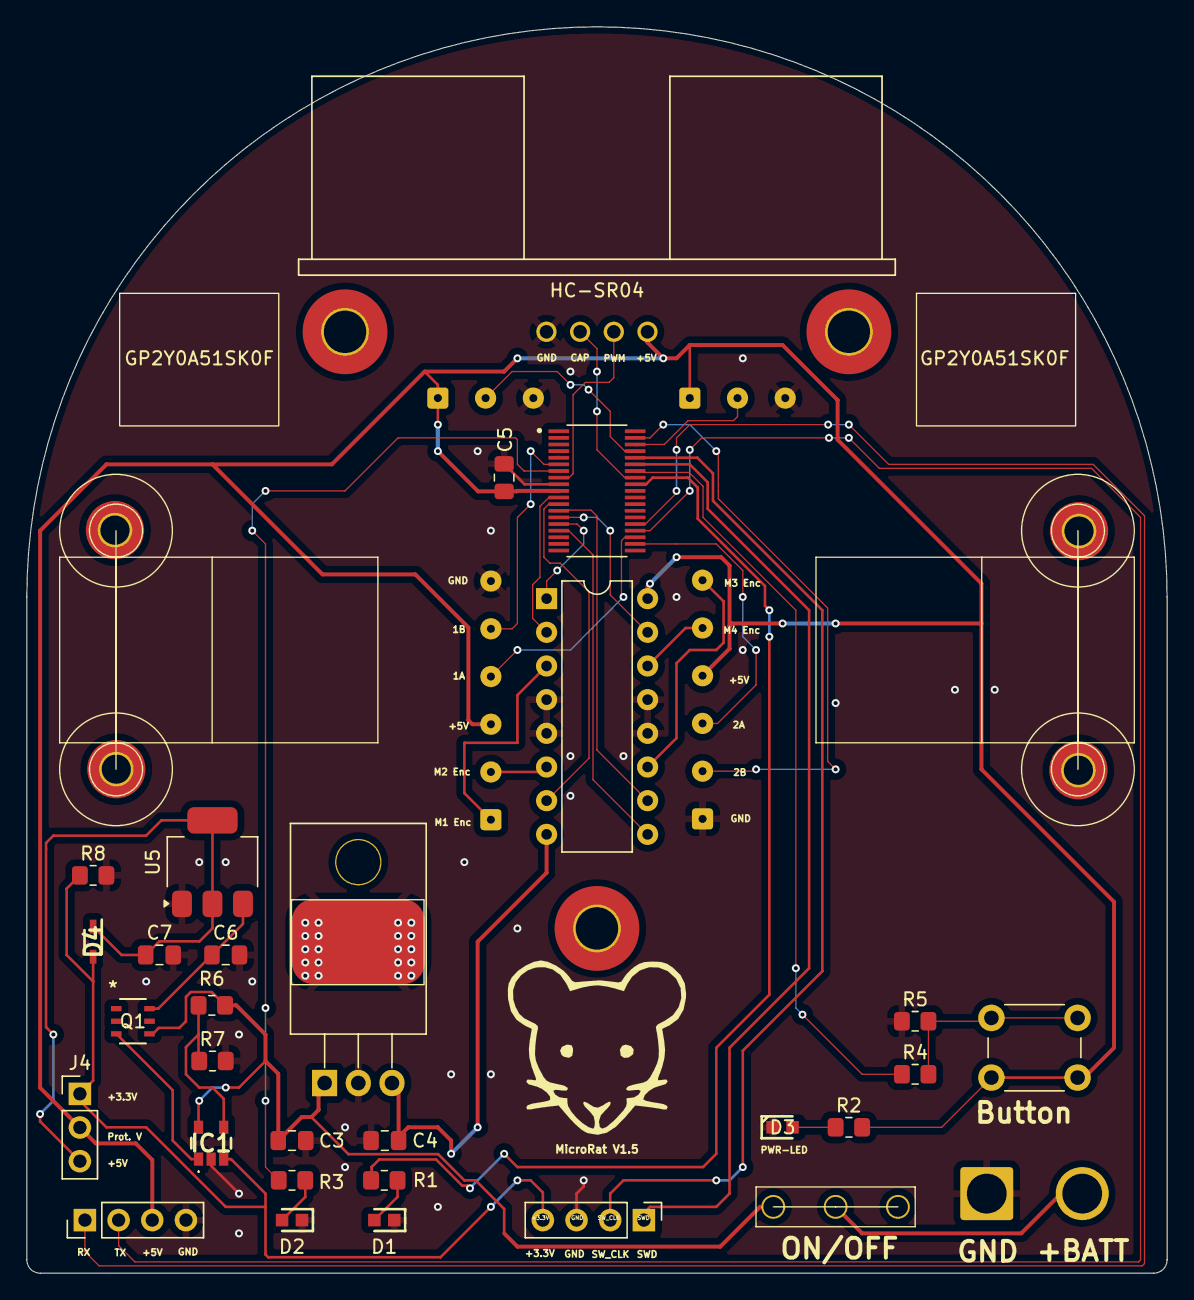
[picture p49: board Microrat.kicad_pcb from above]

Board: 2 copper layers, 86.0 x 94.0 mm, 38 parts (0 on the bottom side), 39 nets.

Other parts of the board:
GP2Y0A51SK0F, GP2Y0A51SK0F#2: Sharp
Motor: Motor_Bracket
Motor#2: Motor_Bracket

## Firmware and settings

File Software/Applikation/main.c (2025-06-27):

/**
 * @file main.c
 * @brief Einstiegspunkt und Hauptschleifensteuerung der Microrat-Anwendung.
 *
 * Dieses Modul bildet das Herzstück des Starts der Microrat-Anwendung.
 * Es ist verantwortlich für die Initialisierung aller notwendigen Hardware- und
 * Softwarekomponenten durch die Nutzung der DAVE APPs.
 * Nach erfolgreicher Initialisierung wird die unendliche Hauptschleife gestartet,
 * welche die kontinuierliche Ausführung der Zustandsmaschine
 * ('RatStateMachine_Update()') sicherstellt.
 *
 * Alle systemweiten Initialisierungsaufrufe, insbesondere die von DAVE generierten,
 * sind hier zentral am Anfang der Anwendung gekapselt, um einen klaren Startpunkt
 * zu gewährleisten.
 *
 * @author Marcus Stake Alvarado
 * @date 2025-06-26
 * @version 1.0
 */
#include "DAVE.h"
#include "Applikation/state_machine.h"
#include "Funktionsschnittstellen/sensors.h"

int main(void) {

	DAVE_Init();           		   	///- Initialisierung der DAVE APPs
	Sensors_Init();					///- Sensoren initialisiert

	// Hauptschleife der Anwendung
	while(true) {
		RatStateMachine_Update();	///- Aktualisiert den aktuellen Zustand der MicroRat und führt entsprechende Aktionen aus
	}
}

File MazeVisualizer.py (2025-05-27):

    
import serial
import time
import sys

# --- KONFIGURATION ---
# Passe diese Werte an dein Setup an:
SERIAL_PORT = 'COM4'    # Oder '/dev/ttyUSB0' oder 'COMx' je nach System und Anschluss
BAUDRATE = 9600         # Muss zur Baudrate deines Mikrokontrollers passen
MAZE_WIDTH = 7          # Breite des Labyrinths (aus deinem C-Code)
MAZE_HEIGHT = 4         # Höhe des Labyrinths (aus deinem C-Code)
# --------------------

# Lookup-Tabelle für Wände (Bit-Positionen wie in deinem C-Code)
# Bit 0: Norden (1)
# Bit 1: Osten (2)
# Bit 2: Süden (4)
# Bit 3: Westen (8)

def parse_maze_data(lines):
    """
    Parst die empfangenen Zeilen und füllt zwei 2D-Arrays:
    eines für die MazeMap-Werte (Wandinformationen) und
    eines für die DistanceMap-Werte (Flood Fill Distanzen).
    """
    maze_map = [[0 for _ in range(MAZE_WIDTH)] for _ in range(MAZE_HEIGHT)]
    distance_map = [[0 for _ in range(MAZE_WIDTH)] for _ in range(MAZE_HEIGHT)] # NEU: Für Distanzwerte

    for line in lines:
        # Teile die Zeile am Komma (jede Zeile kann mehrere [Y][X]:VAL:DIST, Teile haben)
        parts = line.strip().split(',')
        for part in parts:
            if not part: # Leere Strings ignorieren
                continue
            try:
                # Extrahiere Y-Koordinate
                y_str_start = part.find('[') + 1
                y_str_end = part.find(']')
                y = int(part[y_str_start:y_str_end])

                # Extrahiere X-Koordinate
                x_str_start = part.find('[', y_str_end) + 1
                x_str_end = part.find(']', x_str_start)
                x = int(part[x_str_start:x_str_end])

                # Teile den Rest des Strings bei den Doppelpunkten, um Maze- und Distanzwert zu erhalten
                # Beispiel: ":10:0"
                values_portion = part[part.find(':', x_str_end) + 1:]
                
                # Jetzt die Werte aufsplitten (z.B. "10" und "0")
                values_split = values_portion.split(':')

                if len(values_split) == 2:
                    maze_val = int(values_split[0])
                    dist_val = int(values_split[1])
                else:
                    print(f"Warnung: Unerwartetes Format für Werte in '{part}'. Erwarte 'VAL:DIST'.", file=sys.stderr)
                    continue
                
                if 0 <= y < MAZE_HEIGHT and 0 <= x < MAZE_WIDTH:
                    maze_map[y][x] = maze_val
                    distance_map[y][x] = dist_val # NEU: Distanz speichern
                else:
                    print(f"Warnung: Ungültige Koordinaten [{y}][{x}] für Wert {maze_val}:{dist_val}. Ignoriere.", file=sys.stderr)

            except (ValueError, IndexError) as e:
                print(f"Warnung: Konnte Teil '{part}' nicht parsen. Fehler: {e}", file=sys.stderr)
                continue
    return maze_map, distance_map # NEU: Beide Karten zurückgeben

def draw_maze(maze_map, distance_map):
    """
    Zeichnet das Labyrinth im ASCII-Format basierend auf der 2D-Array-Karte
    und zeigt die Distanzwerte innerhalb der Zellen an.
    """
    print("\n--- ERFASSTES LABYRINTH (mit Distanzen) ---")
    print("\n")
    
    # Iteriere von der höchsten Y-Koordinate nach unten,
    # um das Labyrinth so darzustellen, dass [0][0] unten links ist.
    for y in range(MAZE_HEIGHT - 1, -1, -1):
        # Erste Zeile: Obere Wände
        line1 = "o" # Startecke
        for x in range(MAZE_WIDTH):
            cell_value = maze_map[y][x]
            # Prüfe Nordwand (Bit 0)
            if (cell_value & 0b0001) > 0: # Nordwand vorhanden
                line1 += "---o"
            else: # Keine Nordwand
                line1 += "   o"
        print(line1)

        # Zweite Zeile: Vertikale Wände und Zellinhalt (Distanzwert)
        line2 = ""
        # Zeichne die linke Begrenzung der ersten Zelle in der Reihe (Westwand von [y][0])
        if (maze_map[y][0] & 0b1000) > 0: # Westwand vorhanden (Bit 3)
            line2 += "|"
        else:
            line2 += " "

        for x in range(MAZE_WIDTH):
            cell_maze_value = maze_map[y][x]
            cell_dist_value = distance_map[y][x] 
            
            # Formatiere den Distanzwert für die Zellmitte
            if cell_dist_value == 9999: # UNVISITED_DISTANCE
                line2 += "?? "
            else:
                line2 += f"{cell_dist_value:2d} " # Formatiert auf 2 Stellen (z.B. " 5" oder "12")
            
            # ZUSÄTZLICHE PRÜFUNG: Zeichne die rechte Wand (Ostwand) der aktuellen Zelle (x,y)
            # Diese Wand ist auch die linke Wand der Zelle (x+1, y)
            if (cell_maze_value & 0b0010) > 0: # Ostwand vorhanden (Bit 1)
                line2 += "|"
            else:
                line2 += " "
        print(line2)

    # Letzte Zeile: Untere Wände der untersten Reihe (y=0)
    line3 = "o"
    for x in range(MAZE_WIDTH):
        cell_value = maze_map[0][x] # Nur die Südwände der untersten Reihe sind relevant
        # Prüfe Südwand (Bit 2)
        if (cell_value & 0b0100) > 0: # Südwand vorhanden
            line3 += "---o"
        else: # Keine Südwand
            line3 += "   o"
    print(line3)
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

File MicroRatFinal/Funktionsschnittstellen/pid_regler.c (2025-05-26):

#include <stdio.h>
#include <stdlib.h>
#include <math.h>
#include "Dave.h"
#include "Funktionsschnittstellen/pid_regler.h"
#include "Funktionsschnittstellen/movement.h"
#include "Funktionsschnittstellen/sensors.h"
#include "Hardwaresteuerung/hal_motor.h"
#include "Hardwaresteuerung/hal_encoder.h"

volatile float distanceGoal_R = 0.0f;
volatile float distanceGoal_L = 0.0f;
volatile float integral_error_R = 0.0f;
volatile float integral_error_L = 0.0f;
volatile float last_error_L = 0.0f;
volatile float last_error_R = 0.0f;

void ControllerHandler(){
	UpdatePID();
}

void UpdatePID() {
	float kp_current, ki_current , kd_current;
	if (isTurning) {
		kp_current = KP_TURN;
		ki_current = KI_TURN;
		kd_current = KD_TURN;
	} else {
		kp_current = KP_STRAIGHT;
		ki_current = KI_STRAIGHT;
		kd_current = KD_STRAIGHT;
	}
	// Encoder-Werte in Millimeter abrufen
	float current_pos_L_mm = GetEncoderLeft_mm();
	float current_pos_R_mm = GetEncoderRight_mm();

	// Fehlerberechnung für jedes Rad
	float error_L = distanceGoal_L - current_pos_L_mm;
	float error_R = distanceGoal_R - current_pos_R_mm;

	// Integralanteile aktualisieren
	integral_error_L += error_L;
	integral_error_R += error_R;

	// Integralbegrenzung
	if (integral_error_L > INTEGRAL_LIMIT) integral_error_L = INTEGRAL_LIMIT;
	if (integral_error_L < -INTEGRAL_LIMIT) integral_error_L = -INTEGRAL_LIMIT;
	if (integral_error_R > INTEGRAL_LIMIT) integral_error_R = INTEGRAL_LIMIT;
	if (integral_error_R < -INTEGRAL_LIMIT) integral_error_R = -INTEGRAL_LIMIT;

	// P, I, D Anteile
	float proportionalCorrection_L = kp_current * error_L;
	float integralCorrection_L = ki_current * integral_error_L;
	float derivativeCorrection_L = kd_current * (error_L - last_error_L);

	float proportionalCorrection_R = kp_current * error_R;
	float integralCorrection_R = ki_current * integral_error_R;
	float derivativeCorrection_R = kd_current * (error_R - last_error_R);

	float currentEncoderDifference = current_pos_R_mm - current_pos_L_mm;
	float gleichlaufError = currentEncoderDifference;
	float gleichlaufKorrektur = KP_GLEICHLAUF * gleichlaufError;

	// Gesamte PWM-Werte
	int pwmL = (int)(proportionalCorrection_L + integralCorrection_L + derivativeCorrection_L + gleichlaufKorrektur);
	int pwmR = (int)(proportionalCorrection_R + integralCorrection_R + derivativeCorrection_R - gleichlaufKorrektur);

	// PWM-Werte begrenzen und sicherstellen, dass sie positiv sind fuer MotorsSetSpeed
	pwmL = (pwmL > PWM_MAX) ? PWM_MAX : pwmL;
	pwmR = (pwmR > PWM_MAX) ? PWM_MAX : pwmR;
	pwmL = (pwmL < -PWM_MAX) ? -PWM_MAX : pwmL;
	pwmR = (pwmR < -PWM_MAX) ? -PWM_MAX : pwmR;

	MotorsSetSpeed(abs(pwmL), abs(pwmR)); // Bleibt unverändert. Deine MotorsSetX() Funktionen müssen die Richtung setzen.

	last_error_L = error_L;
	last_error_R = error_R;
}

void setPIDGoalD(float distance_R, float distance_L) {
	distanceGoal_L = distance_R;
	distanceGoal_R = distance_L;
}

int PIDdone() {
	static int stableCycleCount = 0;
	float current_pos_L_mm = GetEncoderLeft_mm();
	float current_pos_R_mm = GetEncoderRight_mm();
	// Fehlerberechnung für jedes Rad
	float error_L = distanceGoal_L - current_pos_L_mm;
	float error_R = distanceGoal_R - current_pos_R_mm;
	float gleichlauferror_mm = current_pos_R_mm - current_pos_L_mm;
	if (fabsf(error_L) < 5.0f && fabsf(error_R) < 5.0f && fabsf(gleichlauferror_mm) < 2.0f) {
		stableCycleCount++;
		if (stableCycleCount >= CYCLES_THRESHOLD){
			StopAndSignal();
			return 1;
		}
	} else if (error_L < -5.0f && error_R < -5.0){
	//---FUNKTION WENN ER ÜBERCHIESST UM NICHT DURCHZUDREHEN-------------------------
		MotorsStop();
		while (1) {
		DIGITAL_IO_SetOutputHigh(&DIGITAL_IO_AUGE_1);
		DIGITAL_IO_SetOutputLow(&DIGITAL_IO_AUGE_2);
	    for (volatile int i = 0; i < 500000; i++) {}
		DIGITAL_IO_SetOutputLow(&DIGITAL_IO_AUGE_1);
		DIGITAL_IO_SetOutputHigh(&DIGITAL_IO_AUGE_2);
	    for (volatile int i = 0; i < 500000; i++) {}
	}


	} else {
		stableCycleCount = 0;
	}

	return 0;
}

void ResetPID(){
	for (volatile int i = 0; i < 2000000; i++) {}

	isTurning = 0;

	EncoderReset();

	distanceGoal_R = 0.0f;
	distanceGoal_L = 0.0f;
	integral_error_R = 0.0f;
	integral_error_L = 0.0f;
	last_error_R = 0.0f;
	last_error_L = 0.0f;
}

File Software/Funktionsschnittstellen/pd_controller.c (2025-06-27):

/**
 * @file pd_controller.c
 * @brief Implementierung des PD-Reglers für die präzise Bewegung der MicroRat.
 *
 * Dieses Modul verwaltet die Kernlogik des Proportional-Differential-Reglers (PD-Regler)
 * zur Steuerung der Motoren der MicroRat. Es liest Encoder-Werte, berechnet Fehler
 * relativ zu einem Sollwert, und generiert PWM-Signale für die Motoren.
 * Zusätzlich wird ein Gleichlaufregler implementiert, um Abweichungen zwischen
 * den beiden Rädern zu korrigieren. Das Modul umfasst auch eine grundlegende
 * Logging-Funktionalität zur Analyse des Reglerverhaltens, die über das
 * 'debug_comms'-Modul ausgegeben wird.
 *
 * @author Marcus Stake Alvarado
 * @date 2025-06-26
 * @version 1.0
 *
 * @dependencies
 * - <stdio.h>: Für Standard-E/A-Funktionen
 * - <stdlib.h>: Für Standardbibliotheksfunktionen
 * - <math.h>: Für mathematische Funktionen wie 'fabsf()' und 'copysignf()'
 * - <string.h>: Für String-Manipulationsfunktionen wie 'strlen()'
 * - "Funktionsschnittstellen/pd_controller.h": Enthält die Deklarationen der öffentlichen Schnittstellen und Strukturen dieses Moduls
 * - "Funktionsschnittstellen/movement.h": Für externe Variablen wie 'isTurning'
 * - "Funktionsschnittstellen/debug_comms.h": Für die Debug-Kommunikationsschnittstelle, insbesondere `Debug_Comms_SendBuffer()` zum Senden von Log-Daten über UART
 * - "Funktionsschnittstellen/sensors.h": Für das Auslesen der Encoder in mm
 * - "Funktionsschnittstellen/system_interface.h": Für plattformspezifische Funktionen wie `Delay_ms()`
 * - "Hardwaresteuerung/hal_motor.h": Für die Hardware-Abstraktionsschicht der Motoren
 * - "Hardwaresteuerung/hal_encoder.h": Für die Hardware-Abstraktionsschicht der Encoder
 */
#include <stdio.h>
#include <stdlib.h>
#include <math.h>
#include <string.h>
#include "Funktionsschnittstellen/pd_controller.h"
#include "Funktionsschnittstellen/movement.h"
#include "Funktionsschnittstellen/debug_comms.h"
#include "Funktionsschnittstellen/sensors.h"
#include "Funktionsschnittstellen/system_interface.h"
#include "Hardwaresteuerung/hal_motor.h"
#include "Hardwaresteuerung/hal_encoder.h"

volatile float distanceGoal_R = 0.0f;	///- Sollwert für die zu fahrende Distanz des rechten Rades in Millimetern
volatile float distanceGoal_L = 0.0f;	///- Sollwert für die zu fahrende Distanz des linken Rades in Millimetern
volatile float last_error_L = 0.0f;		///- Letzter Fehlerwert des linken Rades für die Berechnung des D-Anteils in Millimetern
volatile float last_error_R = 0.0f;		///- Letzter Fehlerwert des rechten Rades für die Berechnung des D-Anteils in Millimetern

volatile float signed_current_pos_L = 0.0f;	///- aktuell akkumulierte, vorzeichenbehaftete Position des linken Rades in Millimetern
volatile float signed_current_pos_R = 0.0f;	///- aktuell akkumulierte, vorzeichenbehaftete Position des rechten Rades in Millimetern
volatile float last_abs_encoder_L = 0.0f;	///- letzte absolute Encoder-Wert des linken Rades in Millimetern
volatile float last_abs_encoder_R = 0.0f;	///- letzte absolute Encoder-Wert des rechten Rades in Millimetern
volatile float last_pwmL_calculated = 0.0f;	///- letzte berechnete und angewendete PWM-Wert für den linken Motor
volatile float last_pwmR_calculated = 0.0f;	///- letzte berechnete und angewendete PWM-Wert für den rechten Motor

// --- Interne Variablen für die Logging-Funktionalität ---
uint8_t UART_PD[500];
static PdLogEntry pd_log_buffer[PD_LOG_BUFFER_SIZE];
static volatile int pd_log_index = 0;
static volatile int pd_log_count = 0;
static volatile int pd_update_counter = 0;

/**
 * @brief Haupt-Handler für den PD-Regler-Update-Zyklus.
 *
 * Diese Funktion dient typischerweise als Callback für einen Hardware-Timer-Interrupt.
 * Sie stellt sicher, dass die 'UpdatePD()'-Funktion, die die Kernlogik des Reglers enthält,
 * in festen, regelmäßigen Zeitintervallen von 1ms aufgerufen wird.
 */
#include "Dave.h"

void ControllerHandler(){
	UpdatePD();
}
/**
 * @brief Aktualisiert den Zustand des PD-Reglers und steuert die Motoren.
 *
 * Diese Funktion ist das Herzstück des PD-Reglers und wird periodisch aufgerufen
 * . Sie implementiert die gesamte Regellogik in folgenden Schritten:
 * 1.  **Parameter-Auswahl:** Wählt die passenden KP- und KD-Parameter basierend auf dem aktuellen Bewegungsmodus.
 * 2.  **Encoder-Datenabruf:** Ruft die aktuellen absoluten Encoder-Werte für beide Räder ab in mm.
 * 3.  **Delta-Berechnung & Vorzeichenbehaftung:** Berechnet die Bewegungsdistanz seit dem letzten Update ('delta_L', 'delta_R')
 *       und aktualisiert die vorzeichenbehafteten Gesamtpositionen ('signed_current_pos_L', 'signed_current_pos_R')
 *       basierend auf der aktuellen Motorrichtung ('currentMotorDirectionL/R').
 * 4.  **Fehlerberechnung:** Berechnet den Positionsfehler für jedes Rad als Differenz zwischen Soll- und Ist-Position.
 * 5.  **PD-Anteile:** Berechnet die Proportional- und Derivativanteile der Korrektur für jedes Rad.
 * 6.  **Gleichlaufkorrektur:** Berechnet einen Gleichlauffehler zwischen den Rädern und wendet eine Korrektur an,
 *       um Abweichungen (Schieflage bei Geradeausfahrt, ungleichmäßige Drehung) auszugleichen. Die Logik unterscheidet sich für Geradeausfahrt und Drehbewegung.
 * 7.  **PWM-Begrenzung:** Begrenzt die berechneten PWM-Werte auf den maximal zulässigen Bereich.
 * 8.  **Motorsteuerung:** Setzt die Motor-Geschwindigkeiten mit den finalen, angepassten PWM-Werten über die HAL-Schnittstelle.
 * 9.  **Zustandsaktualisierung:** Speichert die aktuellen Fehler und absoluten Encoder-Werte für die Berechnung des D-Anteils und der Deltas in der nächsten Iteration.
 * 10. **Optionales Logging:** Führt intervallbasiertes Logging der Reglerdaten durch, um das Verhalten analysieren zu können.
 */
void UpdatePD() {
	float kp_current, kd_current;
	if (isTurning) {
		kp_current = KP_TURN;
		kd_current = KD_TURN;
	} else {
		kp_current = KP_STRAIGHT;
		kd_current = KD_STRAIGHT;
	}
	// 1. Encoder-Werte in Millimeter abrufen
	float raw_current_pos_L_mm = GetEncoderLeft_mm();
	float raw_current_pos_R_mm = GetEncoderRight_mm();
	// 2. Delta (Veränderung seit der letzten PID-Iteration) berechnen
	// Hier muss delta_L/R das korrekte Vorzeichen bekommen, da raw_current_pos_X_mm immer positiv ist.
	float delta_L = raw_current_pos_L_mm - last_abs_encoder_L;
	float delta_R = raw_current_pos_R_mm - last_abs_encoder_R;

	if (currentMotorDirectionL == MOTOR_BACKWARD) {
		signed_current_pos_L -= delta_L;
	} else if (currentMotorDirectionL == MOTOR_FORWARD) {
		signed_current_pos_L += delta_L;
	}
	if (currentMotorDirectionR == MOTOR_BACKWARD) {
		signed_current_pos_R -= delta_R;
	} else if (currentMotorDirectionR == MOTOR_FORWARD) {
		signed_current_pos_R += delta_R;
	}

	// Fehlerberechnung für jedes Rad
	float error_L = distanceGoal_L - signed_current_pos_L;
	float error_R = distanceGoal_R - signed_current_pos_R;
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

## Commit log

2024-04-29 Stückliste & KiCAD Modelle
    [Stückliste.xlsx, TEFT4300.step]
2024-05-02 Stückliste_02.05.24
    [Teilliste.xlsx]
2024-05-02 Updated version is up
    [Stückliste.xlsx]
2024-05-15 LDO Motor
    [L7806CV.step]
2024-05-15 Schematic aktuell
    [Microrat.kicad_sch]
2024-05-22 neue Schematic
    [Microrat.kicad_sch]
2024-05-22 XMC neue Flags
    [Microrat.kicad_sch]
2024-05-22 neuste Änderungen
    [Microrat.kicad_sch]
2024-05-22 neue Änderungen
    [Microrat.kicad_pcb, Microrat.kicad_sch]
2024-05-22 Final Heute
    [Microrat.kicad_pcb, Microrat.kicad_sch]
2024-05-30 Upload New File
    [Microrat.kicad_pcb]
2024-06-02 Letzter Stand KiCAD
    [Microrat.kicad_sch, MicroratBU.kicad_pcb]
2024-06-02 alter Stand geloescht
    [MicroRat_v1.0.kicad_pcb, MicroRat_v1.0.kicad_sch]
2024-06-02 Bilder,Fertigungsdaten,3D hinzugefügt
    [1101M2S3CQE1.stp, 150060GS75000--3DModel-STEP-510211.STEP, 150060GS75000.step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]
2024-06-02 Restdateien gelöscht
    [Microrat.kicad_pcb, Microrat.kicad_sch]
2024-06-02 Bessere Struktur
    [Teilliste.xlsx]
2024-10-27 Replace Teilliste.xlsx
    [Teilliste.xlsx]
2025-06-12 neues pcb
    [Microrat.kicad_pcb_neu.kicad_pcb]
2025-06-23 Validierung der Anforderungen
2025-07-27 3D Modelle hinzugefügt für 3D Viewer
    [1101M2S3CQE1.stp, Magnetic Encoder 2598-1.SLDASM, Pololu-Wheel-32x7mm.STEP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]
2025-07-27 KiCAD Dateien in einem Ordner
    [1101M2S3CQE1.stp, 150060GS75000--3DModel-STEP-510211.STEP, 150060GS75000.step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]
2025-07-27 Aufgeräumt: unnötige Dateien gelöscht und Ordnerstruktur bereinigt
2025-07-27 Ordner erstellt für Bilder und Videos
2025-07-27 Aufgeräumt
    [to update.xlsx]
2025-09-26 letzter push für v1.5
    [1101M2S3CQE1.stp, 150060GS75000.step, 150060GS75000.stp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]
